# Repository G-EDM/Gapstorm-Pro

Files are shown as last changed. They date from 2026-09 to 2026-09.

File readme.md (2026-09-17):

</br>
</br>
</br>

```diff
 ______     _______ ______  _______
|  ____ ___ |______ |     \ |  |  |
|_____|     |______ |_____/ |  |  |
```                                                               

</br>
</br>

# G-EDM Gapstorm Pro
</br>
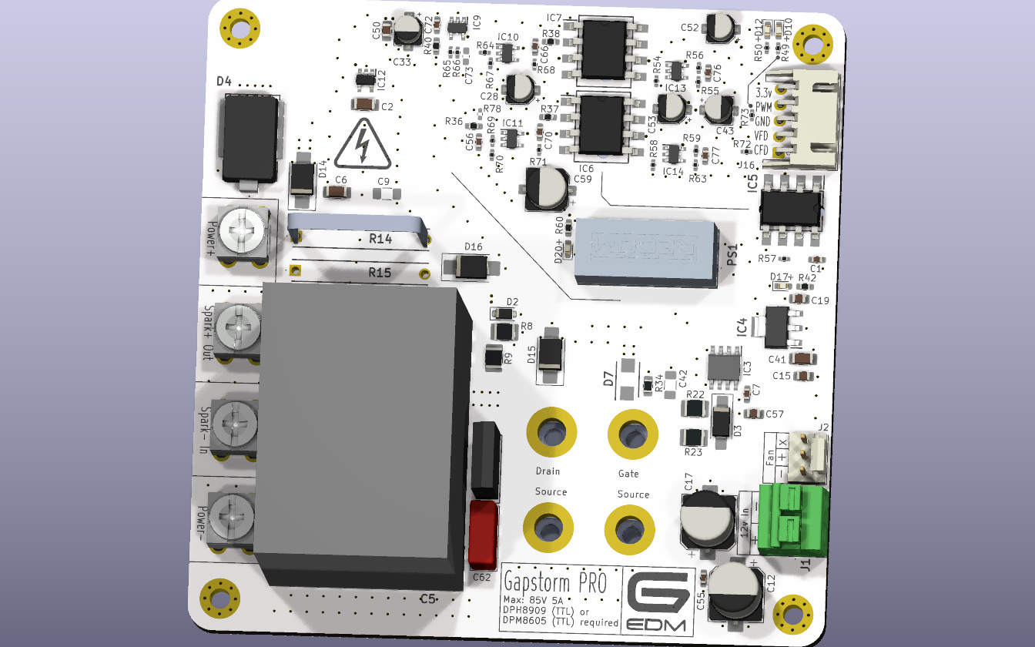
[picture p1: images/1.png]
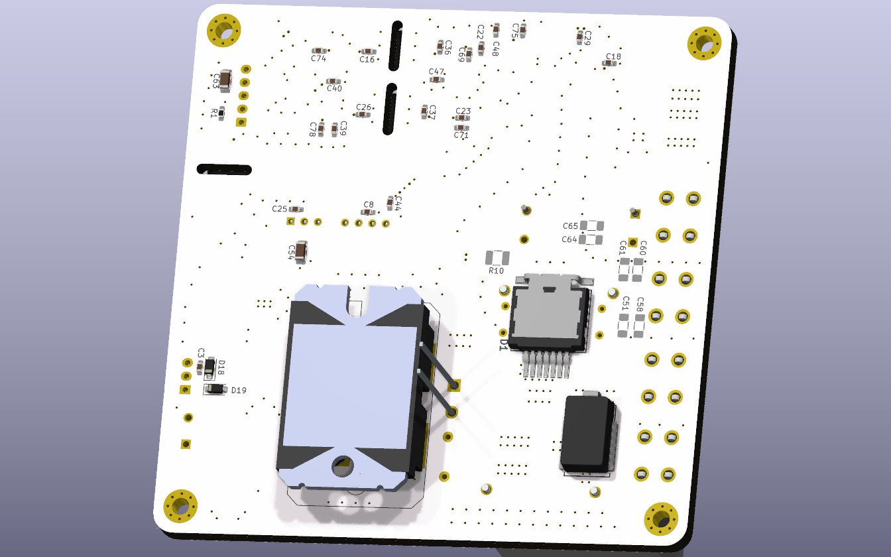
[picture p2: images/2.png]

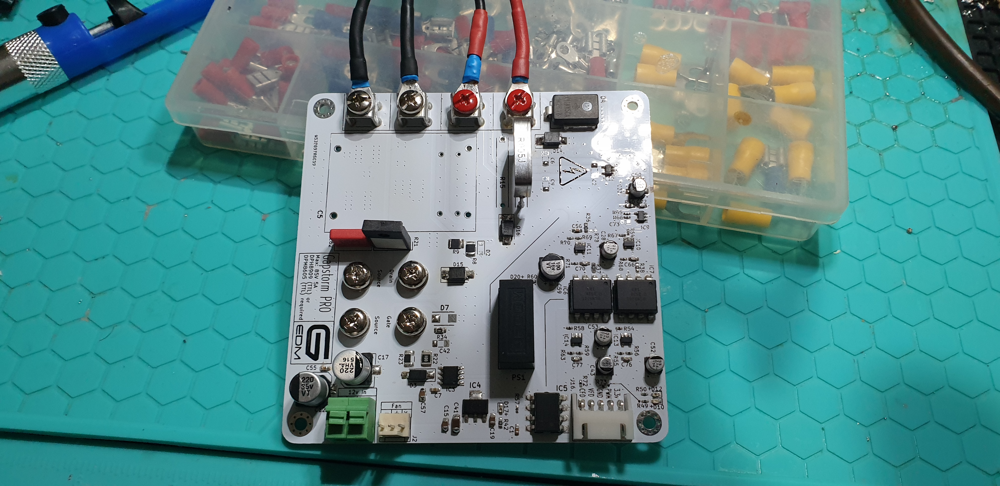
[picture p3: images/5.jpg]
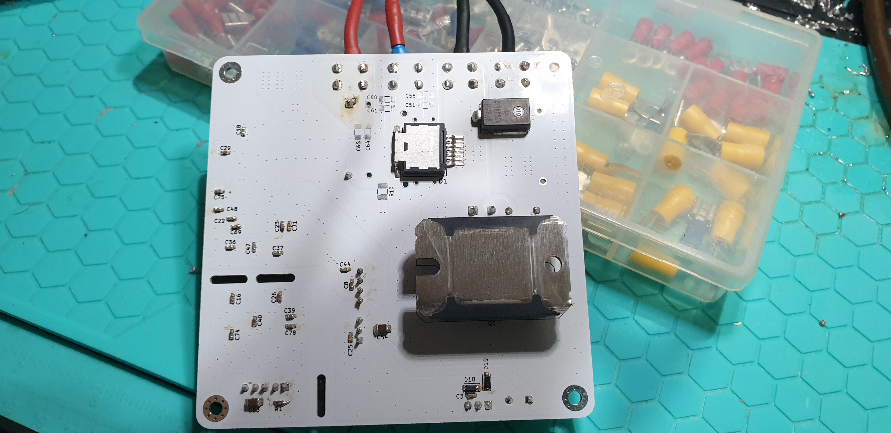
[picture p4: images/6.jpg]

</br>
</br>

The files provided on this repo are fully OpenSource. Have fun. No warranties!

# (fresh update) First test for max current

I just made an initial test for max current without risking the big FET. Connected two parallel IRFP260N to the screw terminals of the board and was able to push 9.5A without breaking anything.

The big FET has a much lower RDSon resistance so there is still a chance that it may not take the full 9.5A but this looks very good so far. No warranty on that but I think the big FET will also be able to manage the full DPH8909 current.

# Warning

This repo contains the upgrade Gapstorm PCB files. I already assembled the board but did not yet had time for real tests. I made a short test shorting the wires at 2.5A and everything looked good. Feedback was very nice. Once I'm done testing, a link to PCBway will be provided and the max current rating published too. For people that have the initial Gapstorm PCB I recommend to change the Gate resistor against a 100R resistor as it is on this board. The Mosfet switching happens so rapid that very high inrush currents can occur that can damage the FET. Even with the 100R resistor the Mosfet is very very fast switching without visible slope on the ESP scope.

</br>
</br>

# About
</br>
The Gapstorm Pro is an improved version for the switching PCB used to control the discharges for EDM machines.
</br>
The PCB is not a stand alone arc generator and requires a DPM8605 or DPH8909 as external power source.
</br>
</br>

# Features
* Mosfet low side switch
* Foil pulse capacitor
* Optically isolated voltage and current feedback
* Optically isolated PWM input
</br>
</br>

# Current and Voltage ratings

* Max input voltage on the power inputs is designed to be 80V. The board has TVS and Zener protection diodes and the input should not exceed 80v. 70V is my personal sweetspot.

* In regards of max current there is still some research that needs to be done. Depending on the Gate resistor and the Foil cap there can occur very high inrush currents that can easily destroy the Mosfet. I changed the Gate resistor to a higher value to prevent this from easily happening but have not produced real max rating data as of now. The Mosfet is expenssive and I am too broke to burn through things.  I'm working on that. 
</br>
</br>

# Wiring

* The board requires a 5P JST XH wire to connect with the motionboard

* A little 12v PSU is required for the gate drive. I use a Mean Well APV-35-12 LED 12V 2.4A for that.

* DPM/DPH positive output connects to Power+ and negative to Power-. Note that those terminals are not next to eachother on this board.

* The two center terminals are the spark terminals. Spark+ connects to the work and Spark- to the electrode.

</br>
</br>

# Important Notes and Warnings

* The Mosfet requires good cooling. It can be screwed onto a heatsick or inside a metal enclosure with the PCB just sitting on top of it.
No isolation barrier between the Mosfet and the colling component is required as the SOT227 Package already provides isolation.

* The switching section is a low side switch and thereforewhile the Mosfet is active DRAIN is switched to GND
The voltage feedback is measured from Work to Electrode using a voltage divider to scale the voltage down and feed it into a sensing circuit.
The nature of this makes a measurement in the OnTime of the switching impossible since the voltage drops close to GND and the input for the sensing circuit looks like a squarewave. This allows proximity sensing but not real gap voltage sensing and then OnTime requires to be filtered out via software.

</br>
</br>

# DPM8605 or DPH8909

* One of those devices is required as source for the spark. I recommend the DPH8909 as it allows higher voltages but the DPM8605 is ok too but limited to 60V.

* Those step down converters come with different interfaces. In order to connect them to the motionboard and have the firmware communicate with them the TTL version is required. Not the RF (Radio) or RS485! Also the baudrate needs to be set at the highest available to match the baudrate used in the firmware. See the manual for the device and search for BAUD. 115200 is what it needs to be and this number is shown on the little display as 115.2 or something.

* Set the current to 1.6A or 1.8A before the first run. This is normally the current I use and safe. Voltage either 70v or if the DPM8605 is used 60v.

</br>
</br>

# G-EDM Wiki

[A little Wiki can be found here](https://gedm.org/wiki)

</br>
</br>

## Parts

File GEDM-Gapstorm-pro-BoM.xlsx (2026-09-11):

 |  |  | G-EDM Pulseboard Gapstorm Pro
Item # | *Designator | *Qty | Manufacturer | *Mfg Part # | Description / Value | *Package/Footprint | Type | Comments
1 | C1, C3, C7, C8, C16, C18, C22, C23, C26, C36, C37, C39, C40, C47, C48, C55, C69, C71, C74, C75, C78, C25, C29, C44 | 24 | Würth Elektronik | 885012206095 | Multilayer Ceramic Capacitors MLCC - SMD/SMT WCAP-CSGP 0.1uF 0603 10% 50V MLCC | C_0603_1608Metric_Pad1.08x0.95mm_HandSolder | SMD
2 | C2 | 1 | Würth Elektronik | 885342008004 | Multilayer Ceramic Capacitors MLCC - SMD/SMT WCAP-CSMH 630V 100pF 1206 5% | C_1206_3216Metric_Pad1.33x1.80mm_HandSolder | SMD
3 | C4, C10 | 0 |  |  | Do not place / Part not used | C_Radial_D12.5mm_H25.0mm_P5.00mm | THT | Do not place / Part not used
4 | C5 | 1 | KEMET | C4AQLBW5700A3LK | Film Capacitors 500V 70 uF 105C 10% 4 Pin LS=37.5 mm AEC-Q200 | C4AQLBW5700A3LK | THT
5 | C6 | 1 | Würth Elektronik | 885382208014 | Multilayer Ceramic Capacitors MLCC - SMD/SMT WCAP-CSST 1206 680pF 10% 2000VDC | C_1206_3216Metric_Pad1.33x1.80mm_HandSolder | SMD
6 | C9, C42, C51, C58, C60, C61, C64, C65 | 0 |  |  | Do not place / Part not used | C_1206_3216Metric_Pad1.33x1.80mm_HandSolder | SMD | Do not place / Part not used
7 | C12, C17 | 2 | Panasonic Industry | EEE-HAV221UAP | Aluminium Electrolytic Capacitors - SMD 220UF 35V HA SMD | CP_Elec_8x10.5 | SMD
8 | C15, C19, C50, C57 | 4 | Samsung Electro-Mechanics | CL21B106KAYQNNE | Multilayer Ceramic Capacitors MLCC - SMD/SMT 10uF 25V X7R 10% 080 0805 | C_0805_2012Metric_Pad1.18x1.45mm_HandSolder | SMD
9 | C28, C33, C43 | 3 | Knowles / Illinois Capacitor | AVS226M16B12T-F | Aluminium Electrolytic Capacitors - SMD 16V 22uF AEC-Q200 | CP_Elec_4x5.4 | SMD
10 | C41, C54 | 2 | Murata Electronics | GRT31CC71E226ME13K | Multilayer Ceramic Capacitors MLCC - SMD/SMT 1206 22uF 25VDC 20% X7S AEC-Q200 | C_1206_3216Metric_Pad1.33x1.80mm_HandSolder | SMD
11 | C52, C53 | 2 | Panasonic Industry | EEE-HAA330WAR | Aluminium Electrolytic Capacitors - SMD 33UF 10V HA SMD | CP_Elec_4x5.4 | SMD
12 | C56 | 1 | Würth Elektronik | 885012206083 | Multilayer Ceramic Capacitors MLCC - SMD/SMT WCAP-CSGP 1000pF 0603 10% 50V MLCC | C_0603_1608Metric_Pad1.08x0.95mm_HandSolder | SMD
13 | C59 | 1 | Knowles / Illinois Capacitor | AVS107M16D16T-F | Aluminium Electrolytic Capacitors - SMD 16V 100uF AEC-Q200 | CP_Elec_6.3x5.4 | SMD
14 | C62 | 1 | WIMA | MKP4J021002B00KSSD | Film Capacitors 630V .01uF 10% | C_Rect_L10.0mm_W4.0mm_P7.50mm_MKS4 | THT
15 | C63 | 1 | Würth Elektronik | 885012208019 | Multilayer Ceramic Capacitors MLCC - SMD/SMT WCAP-CSGP 22uF 1206 10% 10V MLCC | C_1206_3216Metric_Pad1.33x1.80mm_HandSolder | SMD
16 | C66, C70, C76, C77 | 4 | KEMET | C0603C100F5HACAUTO | Multilayer Ceramic Capacitors MLCC - SMD/SMT 50V 10pF 0603 X8R 1% AEC-Q200 | C_0603_1608Metric_Pad1.08x0.95mm_HandSolder | SMD
17 | C72 | 1 | Würth Elektronik | 885012206077 | Multilayer Ceramic Capacitors MLCC - SMD/SMT WCAP-CSGP 100pF 0603 10% 50V MLCC | C_0603_1608Metric_Pad1.08x0.95mm_HandSolder | SMD
18 | C73 | 0 |  |  | Do not place / Part not used | C_0603_1608Metric_Pad1.08x0.95mm_HandSolder | SMD | Do not place / Part not used
19 | D1 | 1 | STMicroelectronics | STTH60RQ06L2Y | Rectifiers Automotive 600 V, 60 A ultrafast high voltage rectifier | STTH60RQ06L2Y | SMD
20 | D2 | 0 |  |  | Do not place / Part not used | D_SOD-123F | SMD | Do not place / Part not used
21 | D3 | 1 | Vishay Semiconductors | B360A-E3/61T | Schottky Diodes & Rectifiers 60 Volt 3.0 Amp 50 Amp IFSM | D_SMA_Handsoldering | SMD
22 | D4, D5 | 2 | Vishay Semiconductors | XFD11K85CA-M3/I | ESD Protection Diodes / TVS Diodes 11KW, 85V 5%, SMD FlatClamping TVS | SM8A27HE32D | SMD
23 | D7 | 0 |  |  | Do not place / Part not used | DIOM5436X244N | SMD | Do not place / Part not used
24 | D10 | 1 | Kingbright | APT1608LVBC/D | Single Colour LEDs 1.6X0.8MM LOW CRNT | LED_0603_1608Metric_Pad1.05x0.95mm_HandSolder | SMD
25 | D12, D17, D20 | 3 | Würth Elektronik | 150060VS83000 | Single Colour LEDs WL-SMCW SMT 0603 Dome Bright Green Typ 300mcd 2V | LED_0603_1608Metric_Pad1.05x0.95mm_HandSolder | SMD
26 | D14, D15, D16 | 3 | Micro Commercial Components (MCC) | SMBJ5378B-TP | Zener Diodes 5W ZENERS SMB 100V | D_SMB_Handsoldering | SMD
27 | D18, D19 | 2 | Diodes Incorporated | 1N4148W-7-F | Small Signal Switching Diodes SURFACE MOUNT FAST SWITCHING DIODE 2A | D_SOD-123 | SMD
28 | IC3 | 1 | IXYS Integrated Circuits | IXDI614SI | Gate Drivers 14-Ampere Low-Side Ultrafast MOSFET Inverting | SOIC127P600X170-9N | SMD
29 | IC4 | 1 | Texas Instruments | LM7805MPX_NOPB | Linear Voltage Regulators 1.5-A 30-V linear vo ltage regulator 4- A 595-LM7805MP/NOPB | SOT230P700X180-4N | SMD
30 | IC5 | 1 | LITEON | 6N137S | High Speed Optocouplers High Speed 10MBd LogicGate Output | SOP254P1016X460-8N | SMD
31 | IC6, IC7 | 2 | Broadcom / Avago | HCNR201-500E | High Linearity Optocouplers 1 Ch 60mW 25mA | SOP254P1230X400-8N | SMD
32 | IC9, IC10, IC11, IC13, IC14 | 5 | Texas Instruments | OPA607QDBVRQ1 | High Speed Operational Amplifiers Automotive 50-MHz lo w-power gain of 6 | SOT95P280X145-5N | SMD
33 | IC12 | 1 | Texas Instruments | INA293B3QDBVRQ1 | Current Sense Amplifiers AEC-Q100 -4-V to 11 0-V 1.3-MHz ultra-fast | SOT95P280X145-5N | SMD
34 | J1 | 1 | Phoenix Contact | 1792863 | Fixed Terminal Blocks PTS 1,5/ 2-5,0-H | 1792863 | THT
35 | J2 | 1 | Molex | 22-11-2037 | Headers & Wire Housings KK 100 Hdr FrLk Vert 3CKT - 2P Voided | FanPinHeader_1x03_P2.54mm_Vertical | THT
36 | J5, J6 | 2 | Keystone Electronics | 7691-2 | Terminals SCREW TERMINAL RED | 8191SEMS | THT
37 | J7 | 1 | Keystone Electronics | 7691-4 | Terminals SCREW TERMINAL WHITE | 8191SEMS | THT
38 | J8 | 1 | Keystone Electronics | 7691-3 | Terminals SCREW TERMINAL BLACK | 8191SEMS | THT
39 | J16 | 1 | JST Commercial | S5B-XH-A(LF)(SN) | Headers & Wire Housings XH HEADER (SIDE) | JST_XH_S5B-XH-A_1x05_P2.50mm_Horizontal | THT
40 | PS1 | 1 | RECOM Power | RS3K-2405SZ/H3 | DC/DC Converters - Through Hole 3W 9-36Vin 5Vout 600mA | RS3K-2405SZ_H3 | THT
41 | Q5 | 1 | IXYS | IXFN230N20T | MOSFET Modules 230A 200V | SOT-227 | Screw mount
42 | R1 | 1 | Panasonic Industry | ERJ-PA3F2000V | Thick Film Resistors - SMD 0603 200ohm 1% Anti-Surge AEC-Q200 | R_0603_1608Metric_Pad0.98x0.95mm_HandSolder | SMD
43 | R8 | 1 | Vishay | CRCW1210620RFKEAHP | Thick Film Resistors - SMD 2.5W 620ohms 1% High Power AEC-Q200 | R_1210_3225Metric_Pad1.30x2.65mm_HandSolder | SMD
44 | R9 | 1 | Vishay | CRCW121010K0FKEAHP | Thick Film Resistors - SMD 2.5W 10Kohms 1% High Power AEC-Q200 | R_1210_3225Metric_Pad1.30x2.65mm_HandSolder | SMD
45 | R10 | 0 |  |  | Do not place / Part not used | R_1210_3225Metric_Pad1.30x2.65mm_HandSolder | SMD | Do not place / Part not used
46 | R14 | 1 | Bourns | MSR5-0R005J1 | Current Sense Resistors - Through Hole MSR-5 0.005 OHM 5% FLAT | MSR50R1F1 | THT
47 | R15 | 0 |  |  | Do not place / Part not used | MSR50R1F1 | THT | Do not place / Part not used
48 | R21 | 1 | Vishay / Sfernice | LTO030F10R00JTE3 | Thick Film Resistors - Through Hole 10ohms 5% | TO508P350X1040X2030-2P | THT
49 | R22 | 1 | Vishay | CRCW1210100RFKEAHP | Thick Film Resistors - SMD 2.5W 100ohms 1% High Power AEC-Q200 | R_1210_3225Metric_Pad1.30x2.65mm_HandSolder | SMD
50 | R23 | 1 | Vishay | CRCW121010R0FKEAHP | Thick Film Resistors - SMD 2.5W 10ohms 1% High Power AEC-Q200 | R_1210_3225Metric_Pad1.30x2.65mm_HandSolder | SMD
51 | R34 | 1 | Würth Elektronik | 560112120013 | Thick Film Resistors - SMD WRIS-RSKS 100 kOhms 1 % 0.25 W 0805 AEC-Q200 | R_0805_2012Metric_Pad1.20x1.40mm_HandSolder | SMD
52 | R36 | 1 | Vishay | CRCW0603200RFKEAHP | Thick Film Resistors - SMD 0.75W 200ohm 1% High Power AEC-Q200 | R_0603_1608Metric_Pad0.98x0.95mm_HandSolder | SMD
53 | R37, R38 | 2 | Vishay | CRCW0603249RFKEAHP | Thick Film Resistors - SMD 0.75W 249 Ohms 1% High Power AEC-Q200 | R_0603_1608Metric_Pad0.98x0.95mm_HandSolder | SMD
54 | R40 | 1 | Vishay | CRCW06030000Z0EAHP | Thick Film Resistors - SMD 0.75W Zeroohm Jumper High Power AEC-Q200 | R_0603_1608Metric_Pad0.98x0.95mm_HandSolder | SMD
55 | R42, R60 | 2 | Würth Elektronik | 560112116053 | Thick Film Resistors - SMD WRIS-RSKS 560 Ohms 1 % 0.1 W 0603 AEC-Q200 | R_0603_1608Metric_Pad0.98x0.95mm_HandSolder | SMD
56 | R49, R50 | 2 | Panasonic Industry | ERJ-PA2D2200X | Thick Film Resistors - SMD 0402 0.5% 220ohm | R_0402_1005Metric_Pad0.72x0.64mm_HandSolder | SMD
57 | R54, R58, R68, R71 | 4 | Würth Elektronik | 560112110019 | Thick Film Resistors WRIS-RSKS 100 kOhms 1 % 0.1 W 0402 AEC-Q200 | R_0402_1005Metric_Pad0.72x0.64mm_HandSolder | SMD
58 | R55, R56, R59, R63 | 4 | Panasonic Industry | ERJ-H2RD2002X | Thick Film Resistors - SMD 0402 20KOhm 0.5% AEC-Q200 | R_0402_1005Metric_Pad0.72x0.64mm_HandSolder | SMD
59 | R57, R64, R69 | 3 | Panasonic Industry | ERJ-PA2D1002X | Thick Film Resistors - SMD 0402 0.5% 10Kohm | R_0402_1005Metric_Pad0.72x0.64mm_HandSolder | SMD
60 | R65 | 1 | Vishay / Draloric | RCS04021K00FKED | Thick Film Resistors - SMD 0.2watt 1Kohms 1% 100ppm | R_0402_1005Metric_Pad0.72x0.64mm_HandSolder | SMD
61 | R66, R72, R73 | 3 | Vishay | CRCW04020000Z0EDHP | Thick Film Resistors - SMD 0.33W Zeroohm Jumper High Power AEC-Q200 | R_0402_1005Metric_Pad0.72x0.64mm_HandSolder | SMD
62 | R67, R70 | 2 | Panasonic Industry | ERJ-PA2D4701X | Thick Film Resistors - SMD 0402 0.5% 4.7Kohm | R_0402_1005Metric_Pad0.72x0.64mm_HandSolder | SMD
63 | R78 | 0 |  |  | Do not place / Part not used | R_0402_1005Metric_Pad0.72x0.64mm_HandSolder | SMD | Do not place / Part not used

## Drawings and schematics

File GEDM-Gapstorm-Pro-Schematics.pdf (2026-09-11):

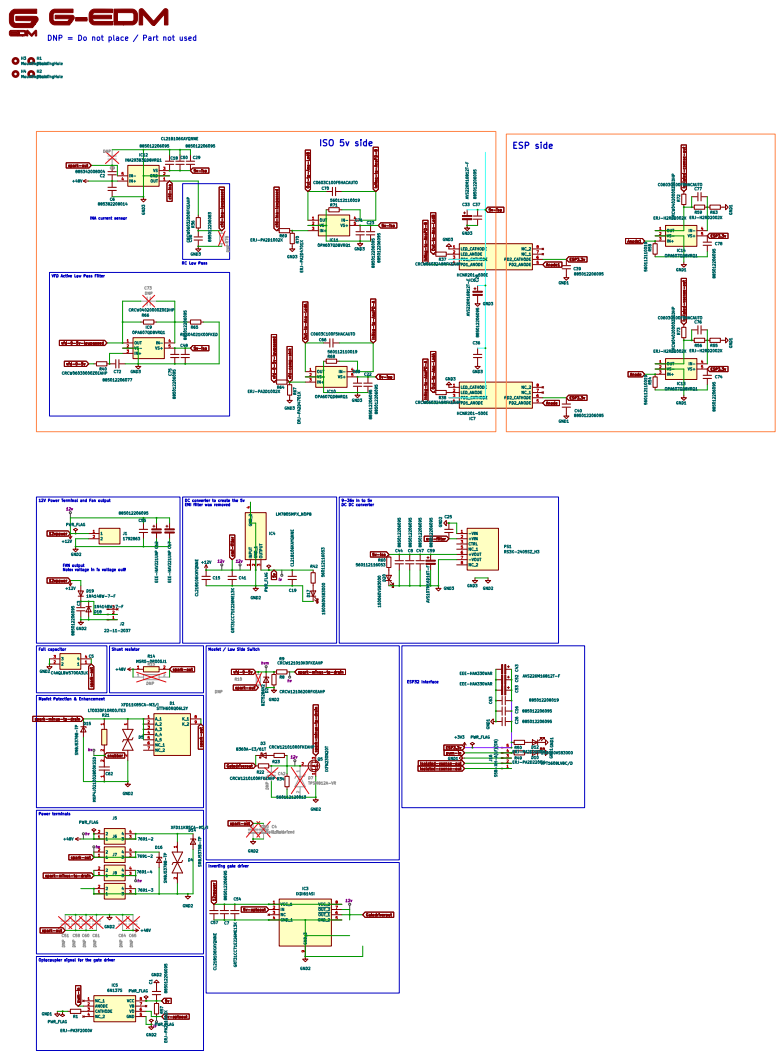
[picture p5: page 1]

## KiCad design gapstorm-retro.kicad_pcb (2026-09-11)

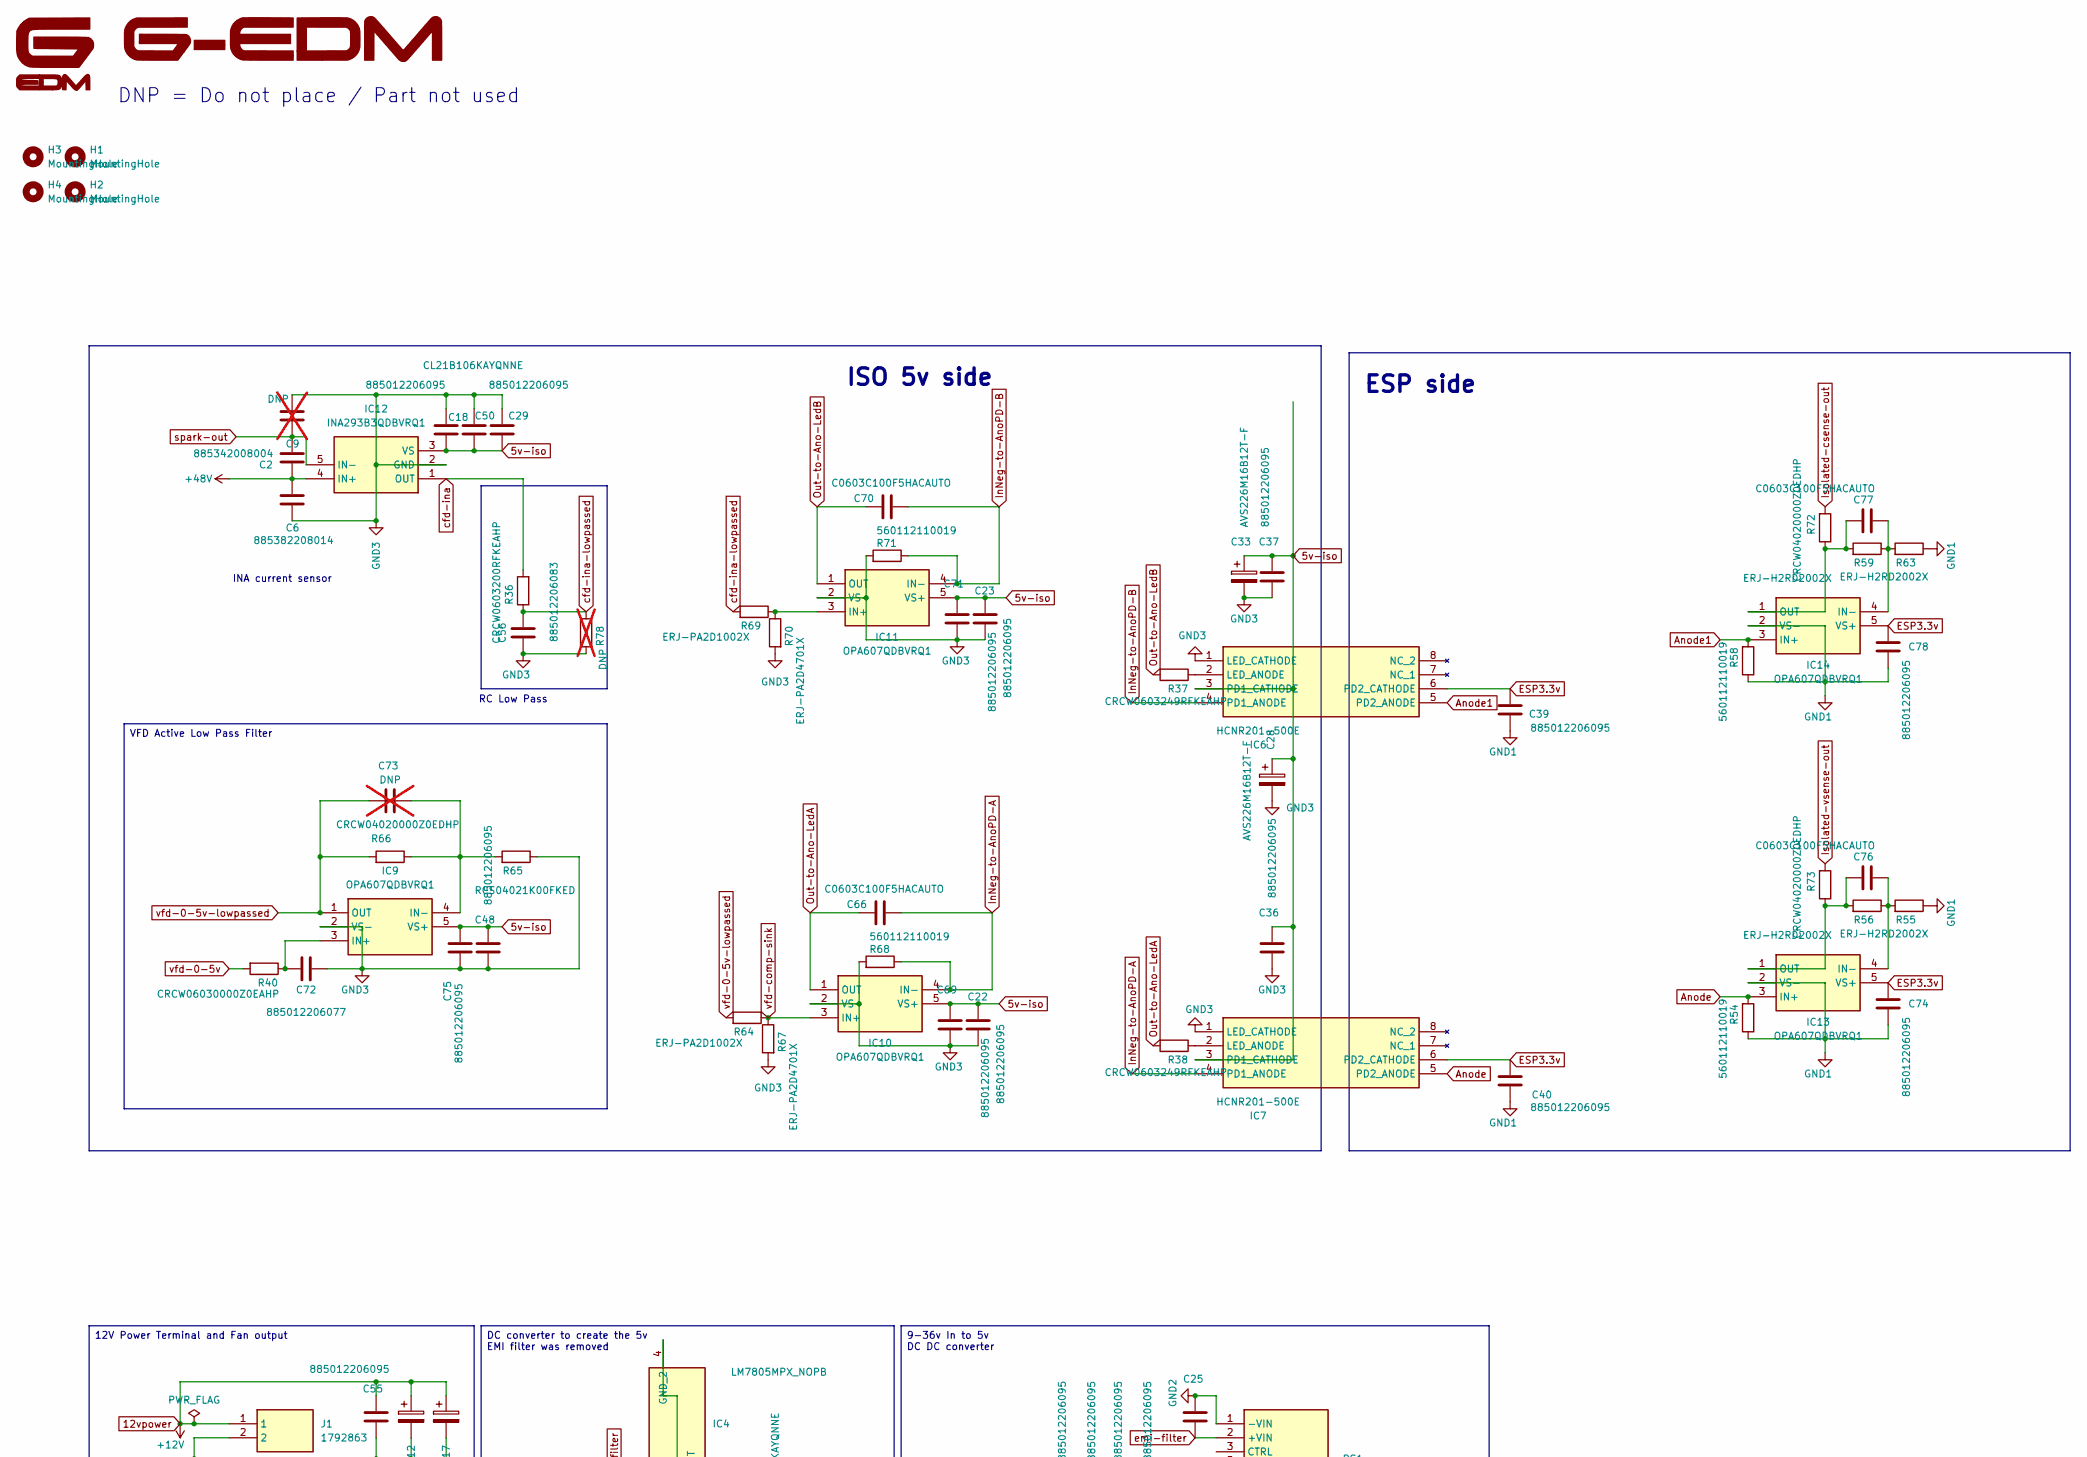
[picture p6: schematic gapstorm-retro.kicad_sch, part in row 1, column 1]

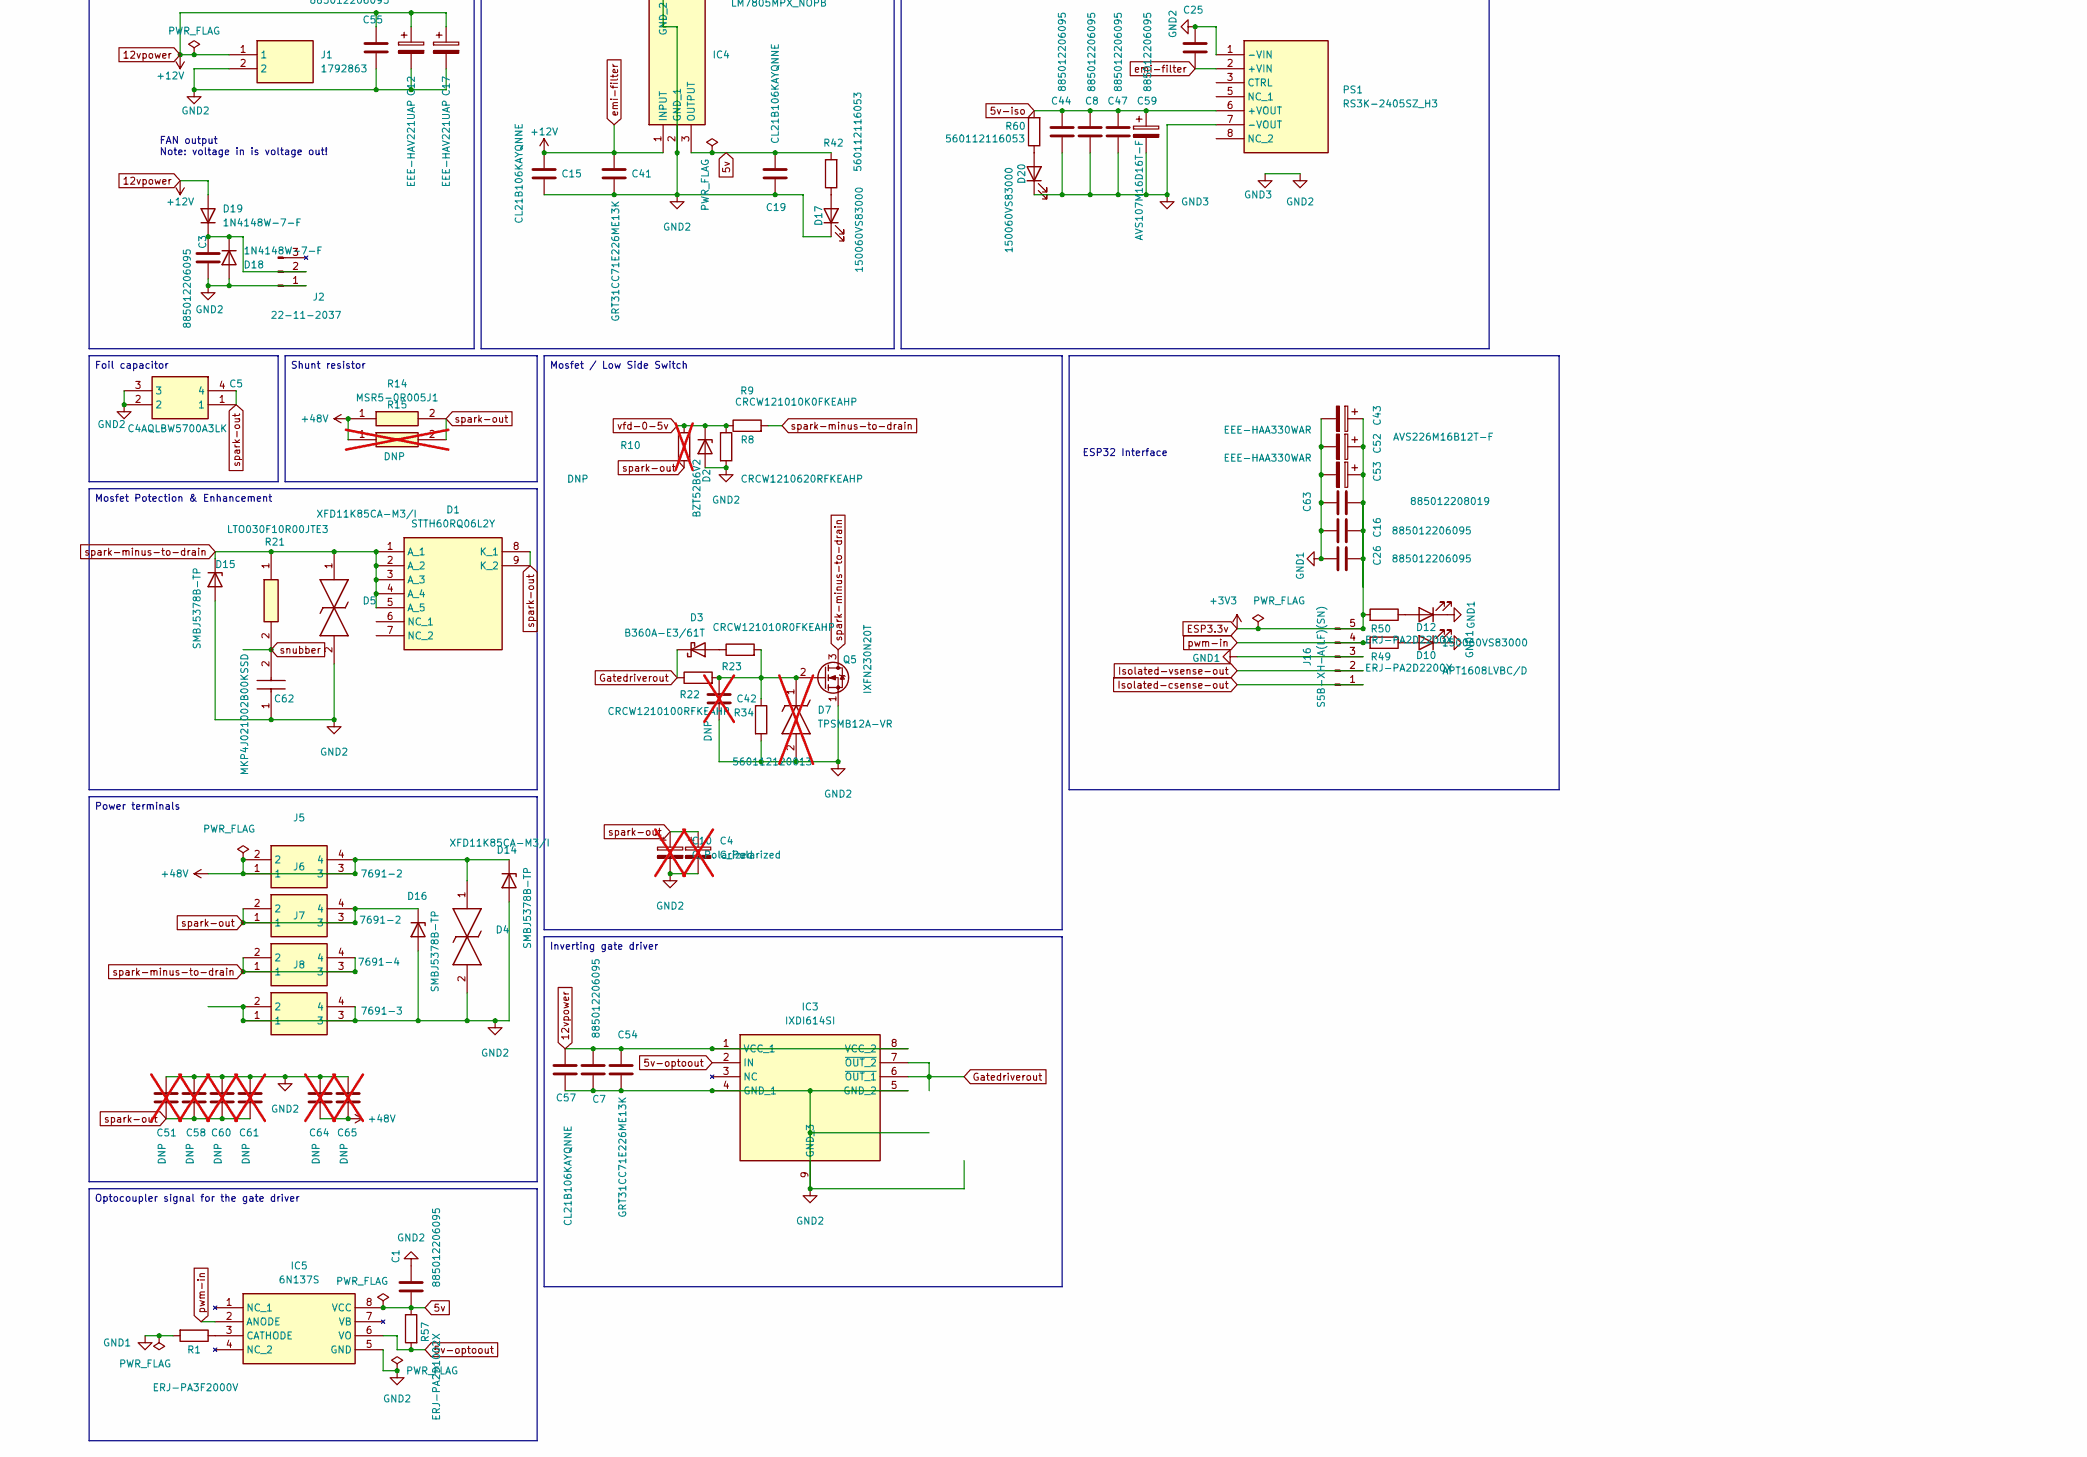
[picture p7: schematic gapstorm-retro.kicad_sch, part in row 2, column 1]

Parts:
C1, C3, C7, C8, C16, C18, C22, C23, C25, C26, C29, C36, C37, C39, C40, C44, C47, C48, C55, C69, C71, C74, C75, C78: 885012206095; C_0603_1608Metric_Pad1.08x0.95mm_HandSolder
C2: 885342008004; C_1206_3216Metric_Pad1.33x1.80mm_HandSolder
C4, C10: C_Polarized; C_Radial_D12.5mm_H25.0mm_P5.00mm; not fitted
C5: C4AQLBW5700A3LK; Manufacturer_Part_Number C4AQLBW5700A3LK; Mouser Part Number 80-C4AQLBW5700A3LK
C6: 885382208014; C_1206_3216Metric_Pad1.33x1.80mm_HandSolder
C9, C42, C51, C58, C60, C61, C64, C65: DNP; C_1206_3216Metric_Pad1.33x1.80mm_HandSolder; not fitted
C12, C17: EEE-HAV221UAP; CP_Elec_8x10.5
C15, C19, C50, C57: CL21B106KAYQNNE; C_0805_2012Metric_Pad1.18x1.45mm_HandSolder
C28, C33, C43: AVS226M16B12T-F; CP_Elec_4x5.4
C41, C54: GRT31CC71E226ME13K; C_1206_3216Metric_Pad1.33x1.80mm_HandSolder
C52, C53: EEE-HAA330WAR; CP_Elec_4x5.4
C56: 885012206083; C_0603_1608Metric_Pad1.08x0.95mm_HandSolder
C59: AVS107M16D16T-F; CP_Elec_6.3x5.4
C62: MKP4J021002B00KSSD; C_Rect_L10.0mm_W4.0mm_P7.50mm_MKS4; Manufacturer_Part_Number FKP2G011001D00KI00; Mouser Part Number 505-FKP2G011001D00KI
C63: 885012208019; C_1206_3216Metric_Pad1.33x1.80mm_HandSolder
C66, C70, C76, C77: C0603C100F5HACAUTO; C_0603_1608Metric_Pad1.08x0.95mm_HandSolder
C72: 885012206077; C_0603_1608Metric_Pad1.08x0.95mm_HandSolder
C73: DNP; C_0603_1608Metric_Pad1.08x0.95mm_HandSolder; not fitted
D1: STTH60RQ06L2Y; Manufacturer_Part_Number STTH60RQ06L2Y
D2: BZT52B6V2; D_SOD-123F
D3: B360A-E3/61T; D_SMA_Handsoldering
D4, D5: XFD11K85CA-M3/I; SM8A27HE32D; Manufacturer_Part_Number PTVS1-086C-H; Mouser Part Number 652-PTVS1-086C-H
D7: TPSMB12A-VR; DIOM5436X244N; Manufacturer_Part_Number TPSMB12A-VR; Mouser Part Number 576-TPSMB12A-VR; not fitted
D10: APT1608LVBC/D; LED_0603_1608Metric_Pad1.05x0.95mm_HandSolder
D12, D17, D20: 150060VS83000; LED_0603_1608Metric_Pad1.05x0.95mm_HandSolder
D14, D15, D16: SMBJ5378B-TP; D_SMB_Handsoldering
D18, D19: 1N4148W-7-F; D_SOD-123
H1, H2, H3, H4: MountingHole; MountingHole_3.2mm_M3_Pad_Via
IC3: IXDI614SI; SOIC127P600X170-9N; Manufacturer_Part_Number IXDI614SI; Mouser Part Number 849-IXDI614SI
IC4: LM7805MPX_NOPB; SOT230P700X180-4N; Manufacturer_Part_Number LM7805MPX/NOPB; Mouser Part Number 595-LM7805MPX/NOPB
IC5: 6N137S; SOP254P1016X460-8N; Manufacturer_Part_Number 6N136S; Mouser Part Number 859-6N136S
IC6, IC7: HCNR201-500E; SOP254P1230X400-8N; Manufacturer_Part_Number HCNR201-500E; Mouser Part Number 630-HCNR201-500E
IC9, IC10, IC11, IC13, IC14: OPA607QDBVRQ1; SOT95P280X145-5N; Manufacturer_Part_Number OPA607QDBVRQ1; Mouser Part Number 595-OPA607QDBVRQ1
IC12: INA293B3QDBVRQ1; SOT95P280X145-5N; Manufacturer_Part_Number INA293B1QDBVRQ1; Mouser Part Number 595-INA293B1QDBVRQ1
J1: 1792863; Manufacturer_Part_Number 1792863; Mouser Part Number 651-1792863
J2: 22-11-2037; FanPinHeader_1x03_P2.54mm_Vertical
J5, J6: 7691-2; 8191SEMS; Manufacturer_Part_Number 8191-SEMS; Mouser Part Number 534-8191-SEMS
J7: 7691-4; 8191SEMS; Manufacturer_Part_Number 8191-SEMS; Mouser Part Number 534-8191-SEMS
J8: 7691-3; 8191SEMS; Manufacturer_Part_Number 8191-SEMS; Mouser Part Number 534-8191-SEMS
J16: S5B-XH-A(LF)(SN); JST_XH_S5B-XH-A_1x05_P2.50mm_Horizontal
PS1: RS3K-2405SZ_H3; RS3K2405SZH3; Manufacturer_Part_Number RS3K-2405SZ/H3; Mouser Part Number 919-RS3K-2405SZ/H3
Q5: IXFN230N20T; SOT-227
R1: ERJ-PA3F2000V; R_0603_1608Metric_Pad0.98x0.95mm_HandSolder
R8: CRCW1210620RFKEAHP; R_1210_3225Metric_Pad1.30x2.65mm_HandSolder
R9: CRCW121010K0FKEAHP; R_1210_3225Metric_Pad1.30x2.65mm_HandSolder
R10: DNP; R_1210_3225Metric_Pad1.30x2.65mm_HandSolder; not fitted
R14: MSR5-0R005J1; MSR50R1F1; Manufacturer_Part_Number MSR5-0R1F1
R15: DNP; MSR50R1F1; Manufacturer_Part_Number MSR5-0R1F1; not fitted
R21: LTO030F10R00JTE3; TO508P350X1040X2030-2P; Manufacturer_Part_Number LTO030F10R00JTE3; Mouser Part Number 72-LTO030F10R00JTE3
R22: CRCW1210100RFKEAHP; R_1210_3225Metric_Pad1.30x2.65mm_HandSolder
R23: CRCW121010R0FKEAHP; R_1210_3225Metric_Pad1.30x2.65mm_HandSolder
R34: 560112120013; R_0805_2012Metric_Pad1.20x1.40mm_HandSolder
R36: CRCW0603200RFKEAHP; R_0603_1608Metric_Pad0.98x0.95mm_HandSolder
R37, R38: CRCW0603249RFKEAHP; R_0603_1608Metric_Pad0.98x0.95mm_HandSolder
R40: CRCW06030000Z0EAHP; R_0603_1608Metric_Pad0.98x0.95mm_HandSolder
R42, R60: 560112116053; R_0603_1608Metric_Pad0.98x0.95mm_HandSolder
R49, R50: ERJ-PA2D2200X; R_0402_1005Metric_Pad0.72x0.64mm_HandSolder
R54, R58, R68, R71: 560112110019; R_0402_1005Metric_Pad0.72x0.64mm_HandSolder
R55, R56, R59, R63: ERJ-H2RD2002X; R_0402_1005Metric_Pad0.72x0.64mm_HandSolder
R57, R64, R69: ERJ-PA2D1002X; R_0402_1005Metric_Pad0.72x0.64mm_HandSolder
R65: RCS04021K00FKED; R_0402_1005Metric_Pad0.72x0.64mm_HandSolder
R66, R72, R73: CRCW04020000Z0EDHP; R_0402_1005Metric_Pad0.72x0.64mm_HandSolder
R67, R70: ERJ-PA2D4701X; R_0402_1005Metric_Pad0.72x0.64mm_HandSolder
R78: DNP; R_0402_1005Metric_Pad0.72x0.64mm_HandSolder; not fitted

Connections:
5v: C1.1, C19.2, IC4.3 (OUTPUT), IC5.8 (VCC), R42.2, R57.1
5v-iso: C8.2, C18.2, C22.1, C23.1, C28.1, C29.1, C33.1, C36.2, C37.2, C44.1, C47.1, C48.1, C50.1, C59.1, C69.2, C71.2, C75.1, IC6.3 (PD1_CATHODE), IC7.3 (PD1_CATHODE), IC9.5 (VS+), IC10.5 (VS+), IC11.5 (VS+), IC12.3 (VS), PS1.6 (+VOUT), R60.2
5v-optoout: IC3.2 (IN), IC5.6 (VO), R57.2
12vpower: C7.2, C12.1, C15.2, C17.1, C25.1, C41.1, C54.1, C55.1, C57.2, D19.2 (A), IC3.1 (VCC_1), IC3.8 (VCC_2), IC4.1 (INPUT), J1.1, PS1.2 (+VIN)
+48V: C2.2, C6.1, C64.1, C65.1, D4.1, D14.1 (K), IC12.4 (IN+), J5.1, J5.2, J5.3, J5.4, R14.1, R15.1
Anode: IC7.5 (PD2_ANODE), IC13.3 (IN+), R54.2
Anode1: IC6.5 (PD2_ANODE), IC14.3 (IN+), R58.2
ESP3.3v: C16.1, C26.1, C39.1, C40.1, C43.1, C52.1, C53.1, C63.2, C74.1, C78.1, IC6.6 (PD2_CATHODE), IC7.6 (PD2_CATHODE), IC13.5 (VS+), IC14.5 (VS+), J16.5, R50.2
GND1: C16.2, C26.2, C39.2, C40.2, C43.2, C52.2, C53.2, C63.1, C74.2, C78.2, D10.1 (K), D12.1 (K), IC13.2 (VS-), IC14.2 (VS-), J16.3, R1.2, R54.1, R55.1, R58.1, R63.1
GND2: C1.2, C3.1, C4.2, C5.2, C5.3, C6.2, C7.1, C8.1, C9.1, C10.2, C12.2, C15.1, C17.2, C18.1, C19.1, C22.2, C23.2, C25.2, C28.2, C29.2, C33.2, C36.1, C37.1, C41.2, C42.2, C44.2, C47.2, C48.2, C50.2, C51.2, C54.2, C55.2, C56.1, C57.1, C58.2, C59.2, C60.2, C61.2, C62.1, C64.2, C65.2, C69.1, C71.1, C72.1, C75.2, D2.2 (A), D4.2, D5.2, D7.2 (A), D14.2 (A), D15.2 (A), D16.2 (A), D17.1 (K), D18.2 (A), D20.1 (K), IC3.4 (GND_1), IC3.5 (GND_2), IC3.9 (GND_3), IC4.2 (GND_1), IC4.4 (GND_2), IC5.5 (GND), IC6.1 (LED_CATHODE), IC7.1 (LED_CATHODE), IC9.2 (VS-), IC10.2 (VS-), IC11.2 (VS-), IC12.2 (GND), J1.2, J2.1, J8.1, J8.2, J8.3, J8.4, PS1.1 (-VIN), PS1.7 (-VOUT), Q5.1 (S), Q5.4 (S), R8.2, R34.2, R65.1, R67.2, R68.2, R70.2, R71.2, R78.2
Gatedriverout: D3.1 (K), IC3.6 (~OUT_1), IC3.7 (~OUT_2), R22.1
InNeg-to-AnoPD-A: C66.2, IC7.4 (PD1_ANODE), IC10.4 (IN-), R68.1
InNeg-to-AnoPD-B: C70.2, IC6.4 (PD1_ANODE), IC11.4 (IN-), R71.1
Isolated-csense-out: J16.1, R72.2
Isolated-vsense-out: J16.2, R73.2
unnamed: D3.2 (A), R23.1
unnamed: C42.1, D7.1 (K), Q5.2 (G), R22.2, R23.2, R34.1
unnamed: D10.2 (A), R49.1
unnamed: D12.2 (A), R50.1
unnamed: D17.2 (A), R42.1
unnamed: C3.2, D18.1 (K), D19.1 (K), J2.2
unnamed: D20.2 (A), R60.1
unnamed: IC5.3 (CATHODE), R1.1
unnamed: IC6.2 (LED_ANODE), R37.1
unnamed: IC7.2 (LED_ANODE), R38.1
unnamed: C72.2, IC9.3 (IN+), R40.1
unnamed: C73.1, IC9.4 (IN-), R65.2, R66.1
unnamed: IC11.3 (IN+), R69.1, R70.1
unnamed: C76.2, IC13.4 (IN-), R55.2, R56.1
unnamed: C76.1, IC13.1 (OUT), R56.2, R73.1
unnamed: C77.2, IC14.4 (IN-), R59.1, R63.2
unnamed: C77.1, IC14.1 (OUT), R59.2, R72.1
Out-to-Ano-LedA: C66.1, IC10.1 (OUT), R38.2
Out-to-Ano-LedB: C70.1, IC11.1 (OUT), R37.2
cfd-ina: IC12.1 (OUT), R36.2
cfd-ina-lowpassed: C56.2, R36.1, R69.2, R78.1
pwm-in: IC5.2 (ANODE), J16.4, R49.2
snubber: C62.2, R21.2
spark-minus-to-drain: D1.1 (A_1), D1.2 (A_2), D1.3 (A_3), D1.4 (A_4), D1.5 (A_5), D5.1, D15.1 (K), J7.1, J7.2, J7.3, J7.4, Q5.3 (D), R9.2, R21.1
spark-out: C2.1, C4.1, C5.1, C5.4, C9.2, C10.1, C51.1, C58.1, C60.1, C61.1, D1.8 (K_1), D1.9 (K_2), D16.1 (K), IC12.5 (IN-), J6.1, J6.2, J6.3, J6.4, R10.2, R14.2, R15.2
vfd-0-5v: D2.1 (K), R8.1, R9.1, R10.1, R40.2
vfd-0-5v-lowpassed: C73.2, IC9.1 (OUT), R64.2, R66.2
vfd-comp-sink: IC10.3 (IN+), R64.1, R67.1

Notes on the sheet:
FAN output Note: voltage in is voltage out!
DNP = Do not place / Part not used
RC Low Pass
ESP32 Interface
INA current sensor
ESP side
ISO 5v side
VFD Active Low Pass Filter
Shunt resistor
Power terminals
Inverting gate driver
12V Power Terminal and Fan output
Foil capacitor
Optocoupler signal for the gate driver
Mosfet / Low Side Switch
Mosfet Potection & Enhancement
9-36v In to 5v DC DC converter
DC converter to create the 5v EMI filter was removed

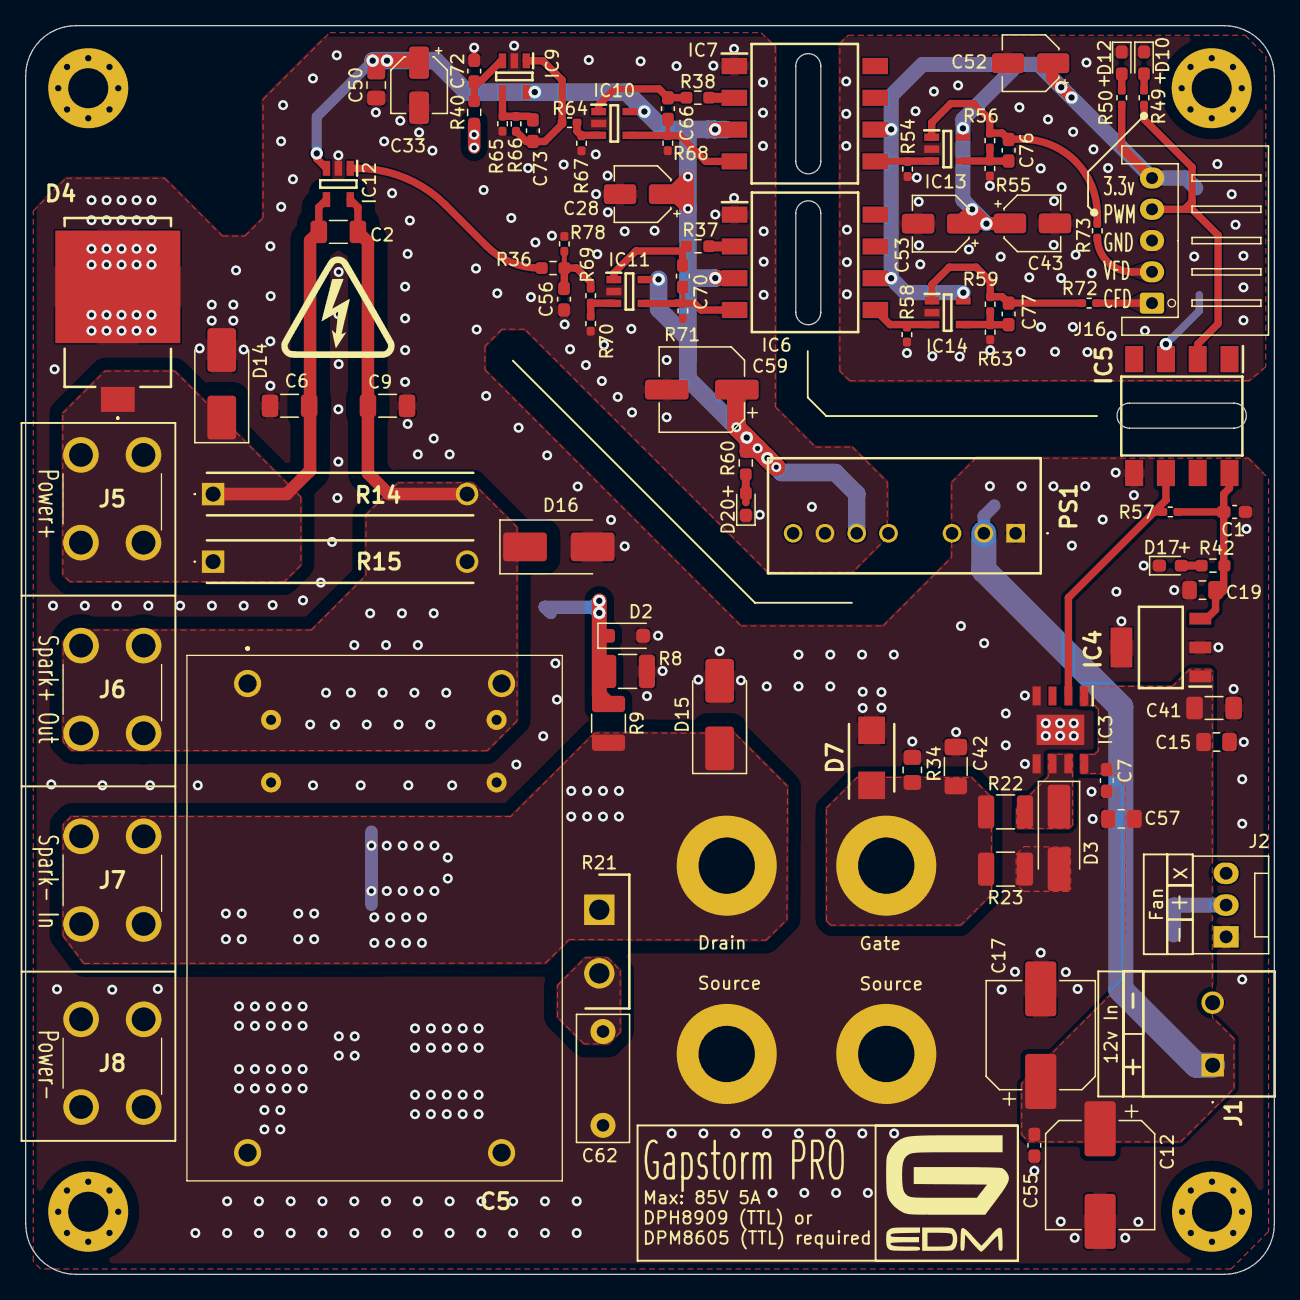
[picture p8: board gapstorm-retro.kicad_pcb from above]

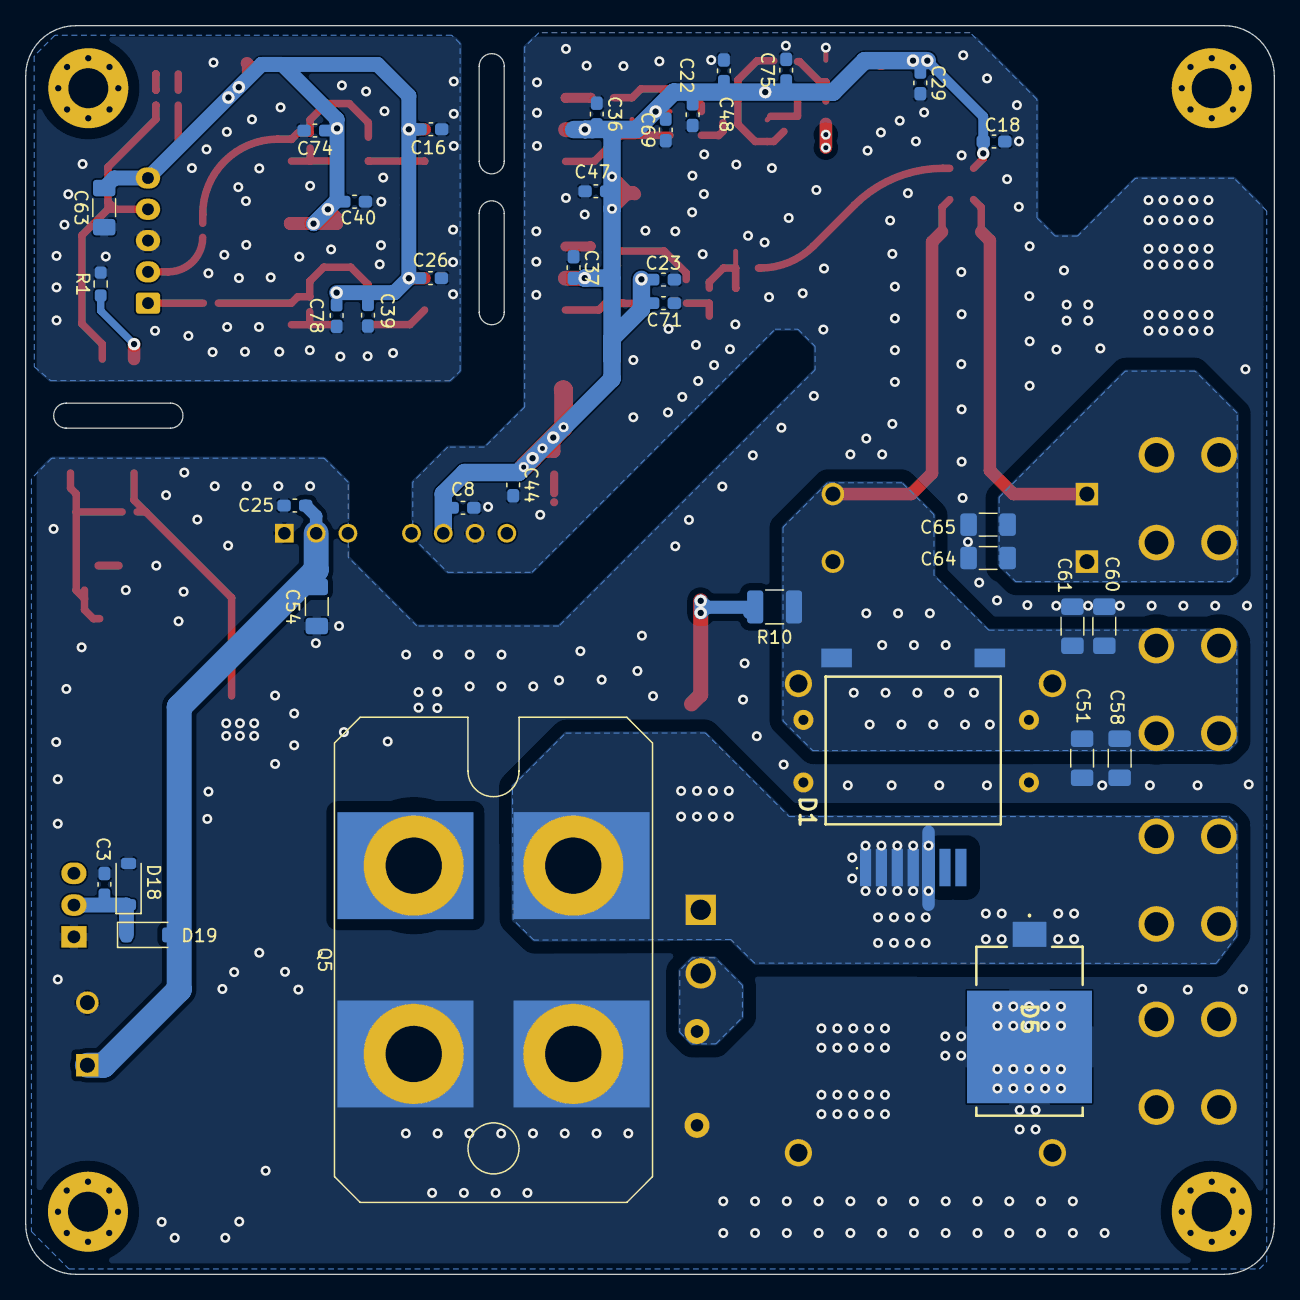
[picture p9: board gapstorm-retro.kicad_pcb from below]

Board: 4 copper layers, 99.8 x 99.8 mm, 135 parts (36 on the bottom side), 43 nets.
